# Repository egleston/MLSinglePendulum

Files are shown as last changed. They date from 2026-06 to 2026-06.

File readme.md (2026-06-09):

# Readme
This repository contains all the files needed to build a simple pendulum.
- **Inverted pendulum (English).pdf**: theory of pendulum kinematics and balance control, English version
- **Inverted pendulum (French).pdf**: theory of pendulum kinematics and balance control, French version
- **ComponentList.md**: Bill of material of the machine
- **Single Pendulum STL**: Folder containing all the 3D-print parts in stl format
- **Single Pendulum Circuit**: Folder containing the pcb (schematic + footprint) drawn on Kicad, this circuit allows to connect electrically all the parts together (motor, controller, etc.)
- **Single Pendulum C++**: Folder containing the source code of the controller, written in C++, in VSCode PlatformIO
- **Single Pendulum SwiftUI**: Folder containing the source code of the program on the computer to set-up the system, to set the parameters and to launch the machine, written in SwiftUI, for MacOS computer
- **Single Pendulum Python**: Folder containing the source code written in Python, only the basics intended to control the pendulum from the computer
- **Single Pendulum Drawings pdf**: Folder containing some assembly drawings and some machined part drawings

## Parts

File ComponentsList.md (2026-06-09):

| Number | Quantity | Description | Supplier | Link |
| --- | --- | --- | --- | ---|
| 001 | 1 | Incremental encoder 2500 CPR | AliExpress  | https://de.aliexpress.com/item/1005008882524645.html |
| 002 | 1 | Teethed belt GT2-6mm 2m | AliExpress  | https://de.aliexpress.com/item/10000401582873.html |
| 003 | 1 | Rail MGN12C 600 mm | AliExpress  | https://de.aliexpress.com/item/1000007480470.html |
| 004 | 1 | Microcontroller ESP32-C3 | AliExpress  | https://de.aliexpress.com/item/1005005967641936.html |
| 005 | 1 | Stepper NEMA17" 40 x 40 | AliExpress  | https://de.aliexpress.com/item/4000022185553.html |
| 006 | 2 | Ball bearing 625 5x16x5 | AliExpress  | https://de.aliexpress.com/item/1005008094013486.html |
| 007 | 1 | Screw UNC 1/4-20 length 1" | AliExpress  | https://de.aliexpress.com/item/1005001377376765.html |
| 008 | 1 | Nut UNC 1/4-20 | AliExpress  | https://de.aliexpress.com/item/1005011995082287.html |
| 009 | 1 | Tube brass OD5 x ID4 mm 200mm | AliExpress  | https://de.aliexpress.com/item/1005007123893361.html |
| 010 | 1 | Bar aluminum OD15 100mm | AliExpress  | https://de.aliexpress.com/item/1005006735658783.html |
| 011 | 1 | Threaded bar M5 x 300 mm | AliExpress  | https://de.aliexpress.com/item/1005008168724880.html |
| 012 | 1 | Driver Trinamic TMC5160-BOB | AliExpress  | https://de.aliexpress.com/item/1005008543014443.html |
| 013 | some | Insert nut for plastic M3 | AliExpress  | https://de.aliexpress.com/item/1005007659182107.html |
| 014 | some | Insert nut for plastic M2 | AliExpress  | https://de.aliexpress.com/item/1005007659182107.html |
| 015 | 1 | PCB connect micro and driver | PCBWay | See folder Single Pendulum Circuit |
| 016 | 1 | Wooden base board 800x200x16 mm | DIY shop | |
| 017 | Some | screws | DIY shop | |
| 101 | 1 | BeltFixture | 3D-print | |
| 102 | 1 | CableClamp | 3D-print | |
| 103 | 1 | CableFixture | 3D-print | |
| 104 | 1 | EncoderFixture | 3D-print | |
| 105 | 2 | MotorFlange | 3D-print | |
| 106 | 1 | MotorPulley | 3D-print | |
| 107 | 1 | PulleyFlange | 3D-print | |
| 108 | 1 | ShaftNozzle | 3D-print | |
| 109 | 1 | ShaftWasher | 3D-print | |
| 110 | 1 | Tensioner | 3D-print | |
| 111 | 1 | TensionerBase | 3D-print | |
| 112 | 1 | TensionerPulley | 3D-print | |
| 113 | 1 | BarFixture | Machined | Aluminum, machined from Bar No 010 |
| 114 | 1 | PulleyHub | Machined | Aluminum, machined from Bar No 010 |
| 115 | 1 | TensionerShaft | Machined | Brass, machined from Tube No 009 |

## Assembly

| Number | Quantity | Description | 
| --- | --- | --- |
| 201 | 1 | Single inverted pendulum |
| 202 | 1 | Tensioner assembly |
| 203 | 1 | Carriage assembly | 
| 204 | 1 | Motor's pulley assembly |
| 205 | 1 | Motor assembly |

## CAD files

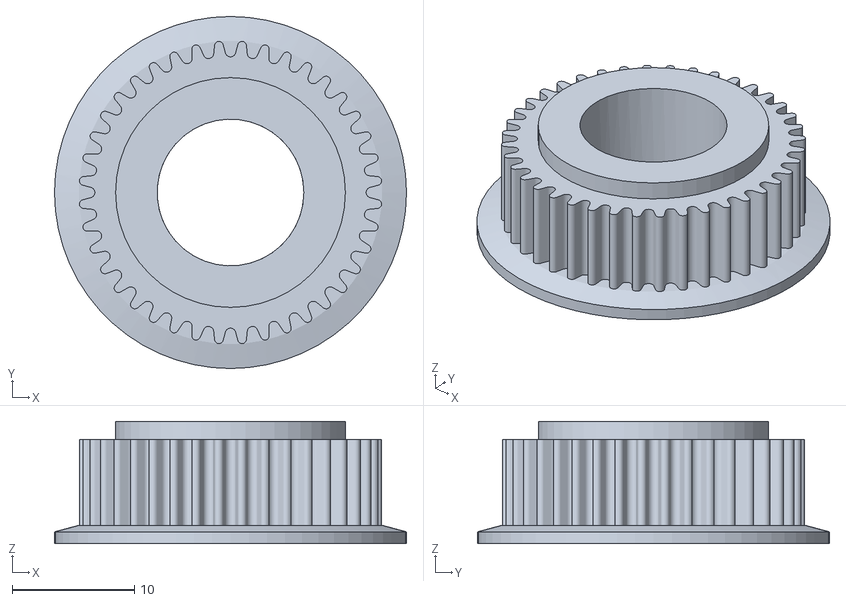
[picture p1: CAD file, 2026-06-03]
Single Pendulum STL/MotorPulley.STL
28.8 x 28.8 x 10.0

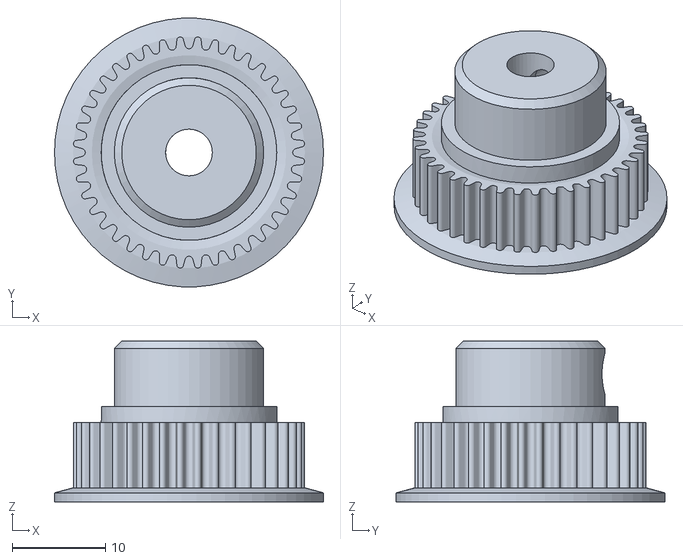
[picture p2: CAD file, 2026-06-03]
Single Pendulum STL/TensionerPulley.STL
28.8 x 28.8 x 17.2

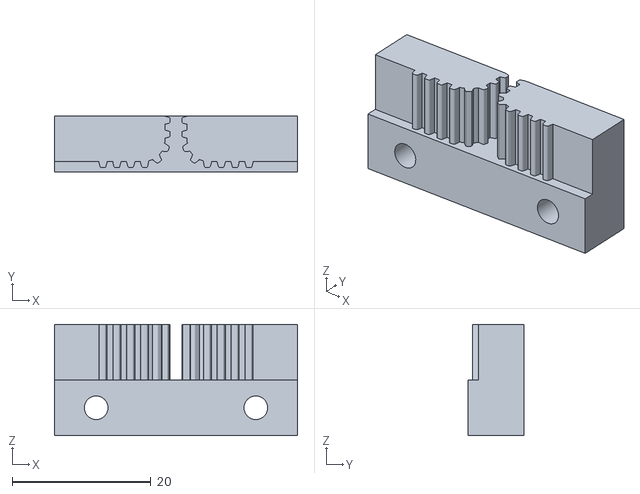
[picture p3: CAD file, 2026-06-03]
Single Pendulum STL/BeltFixture.STL
35.0 x 8.00 x 16.0

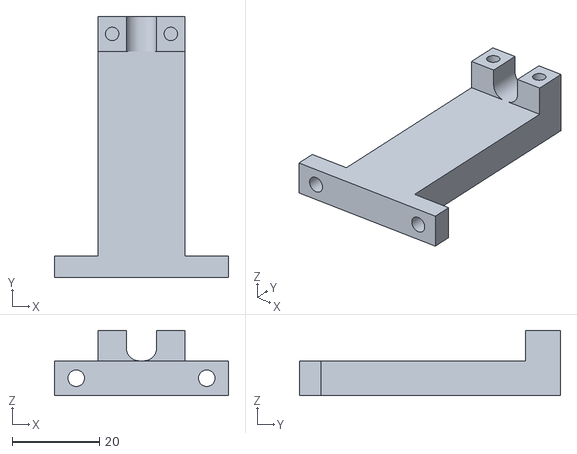
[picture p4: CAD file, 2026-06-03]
Single Pendulum STL/CableFixture.STL
40.0 x 60.0 x 15.0

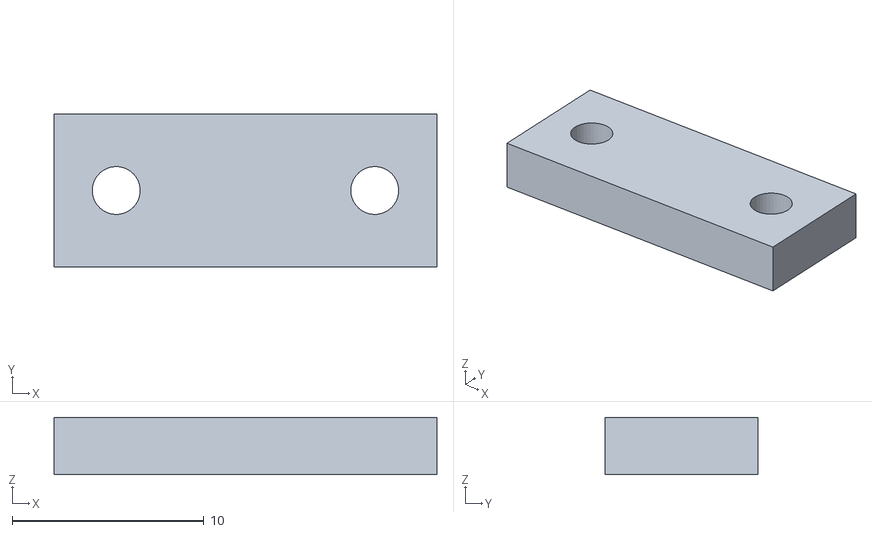
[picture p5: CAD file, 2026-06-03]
Single Pendulum STL/CableClamp.STL
20.0 x 8.00 x 3.00

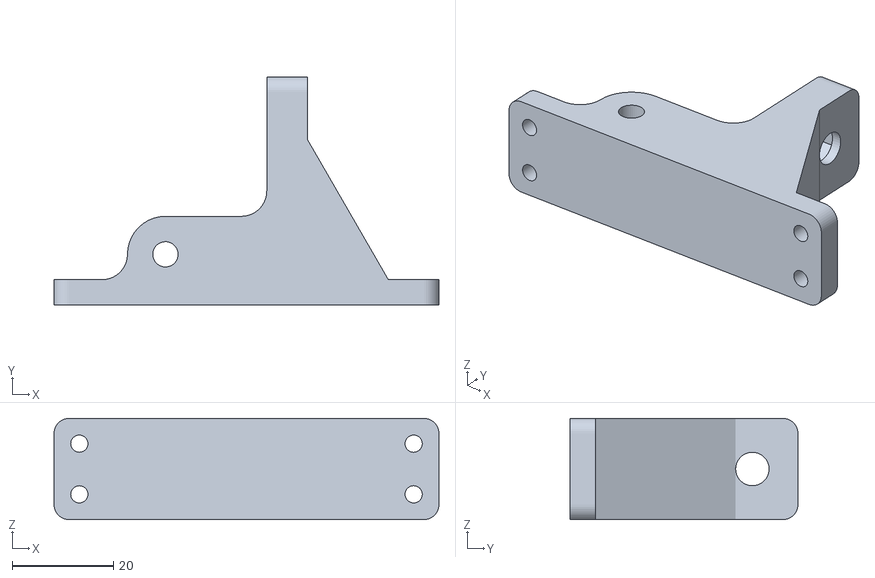
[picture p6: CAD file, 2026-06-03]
Single Pendulum STL/TensionerBase.STL
76.0 x 45.0 x 20.0

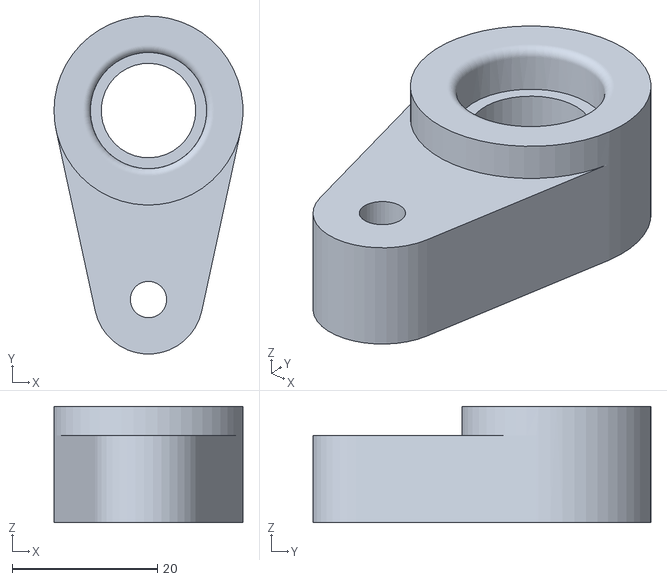
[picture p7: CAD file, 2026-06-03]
Single Pendulum STL/Tensioner.STL
26.0 x 46.5 x 16.0

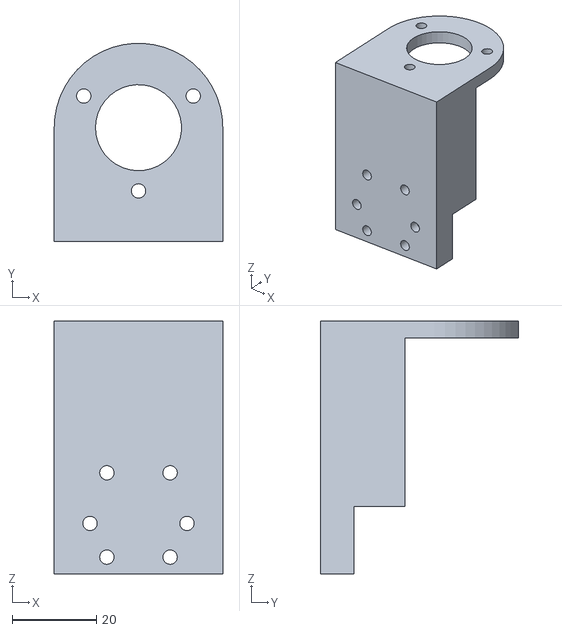
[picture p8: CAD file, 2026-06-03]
Single Pendulum STL/EncoderFixture.STL
40.0 x 47.0 x 60.0

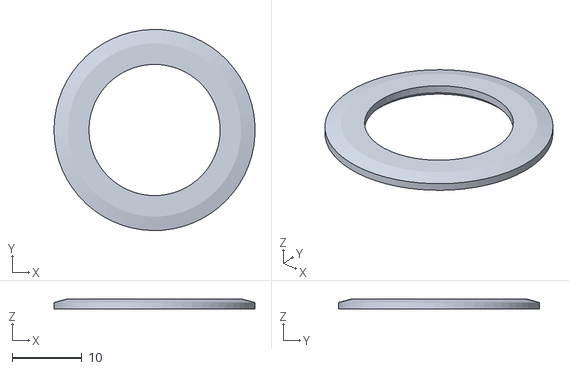
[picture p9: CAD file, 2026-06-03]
Single Pendulum STL/PulleyFlange.STL
28.8 x 28.8 x 1.50

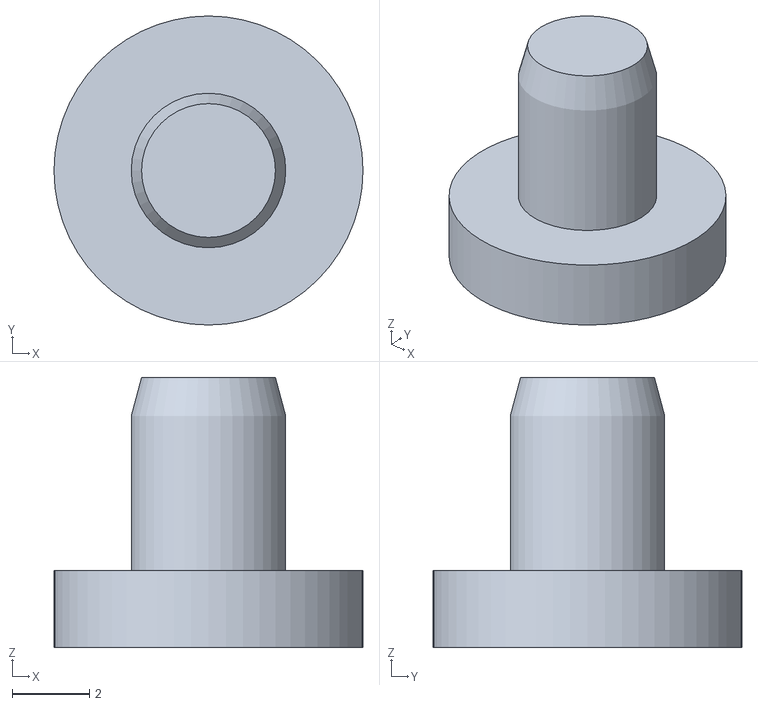
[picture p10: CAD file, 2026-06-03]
Single Pendulum STL/ShaftNozzle.STL
8.00 x 8.00 x 7.00

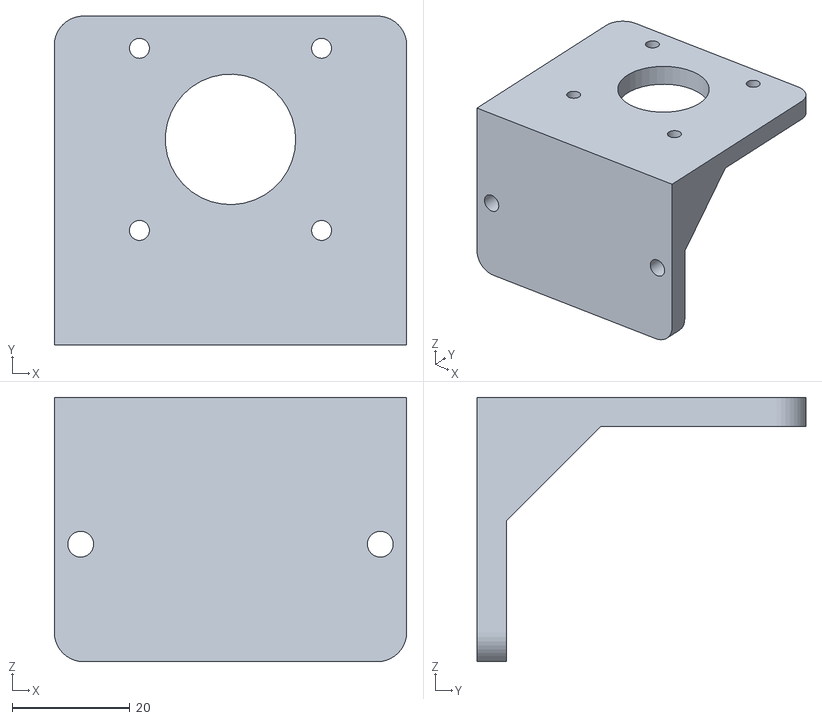
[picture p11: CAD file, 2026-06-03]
Single Pendulum STL/MotorFlange.STL
60.0 x 56.0 x 45.0

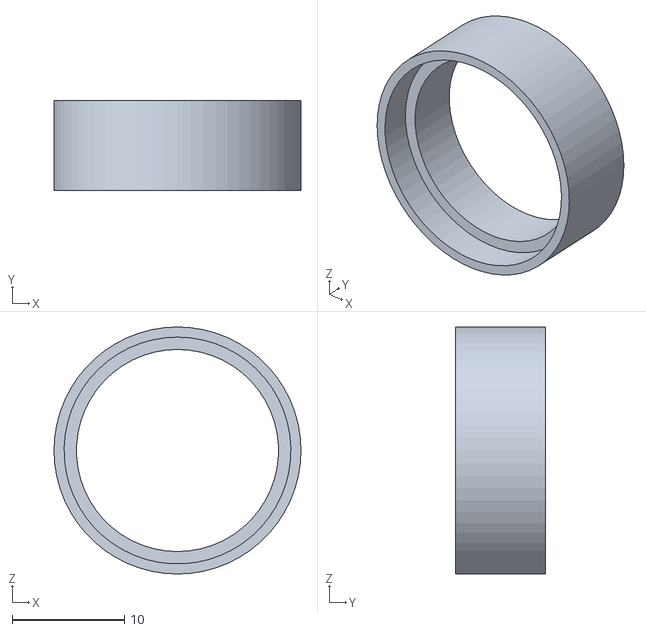
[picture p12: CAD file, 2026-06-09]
Single Pendulum Drawings pdf/WasherEgg.STL
22.0 x 8.00 x 22.0

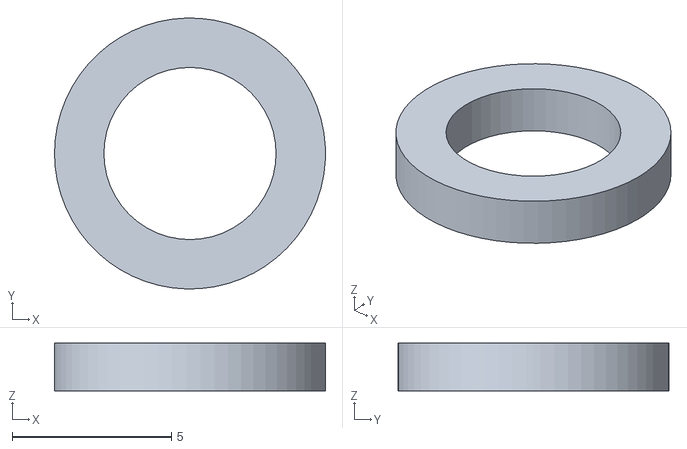
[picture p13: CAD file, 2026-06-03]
Single Pendulum STL/ShaftWasher.STL
8.50 x 8.50 x 1.50

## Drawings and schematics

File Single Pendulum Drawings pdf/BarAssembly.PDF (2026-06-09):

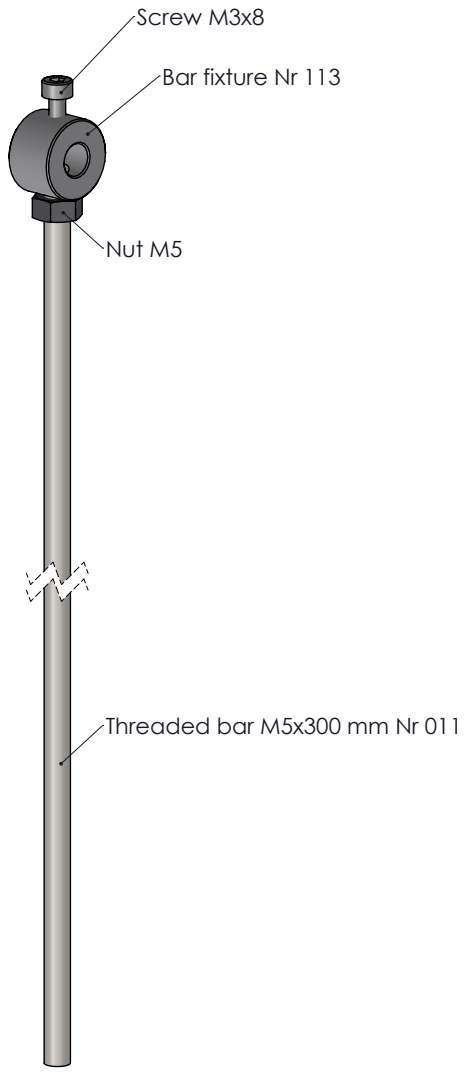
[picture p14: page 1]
Screw M3x8; Nut M5; No dessin; Bar assembly; Dessiné 04.06.2026 - MLa; Echelle 1:1; 04.06.2026 - MLa

Bar fixture Nr 113

Threaded bar M5x300 mm Nr 011

Tolérances ISO 2768-mK

© Ce dessin reste notre propriété et il ne peut être copié, reproduit, communiqué à des tiers ou mis à leur disposition sans notre autorisation écrite.
Bar assembly-M. Laoun-jeudi, 4 juin 2026 20:51:59

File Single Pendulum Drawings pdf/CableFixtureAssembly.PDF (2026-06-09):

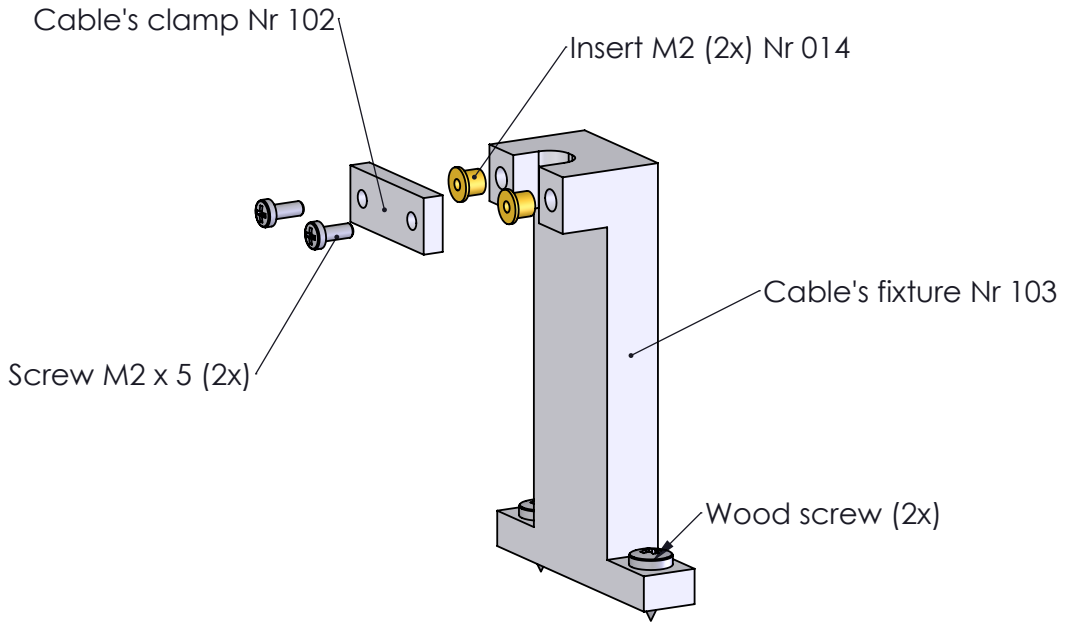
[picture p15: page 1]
Screw M2 x 5 (2x); Insert M2 (2x) Nr 014; Wood screw (2x); No dessin; Cable's fixture assembly; Dessiné 04.06.2026 - MLa; Echelle 1:1; 04.06.2026 - MLa

Cable's clamp Nr 102

Cable's fixture Nr 103

Tolérances ISO 2768-mK

© Ce dessin reste notre propriété et il ne peut être copié, reproduit, communiqué à des tiers ou mis à leur disposition sans notre autorisation écrite.
CableFixtureAssembly-M. Laoun-jeudi, 4 juin 2026 21:14:57

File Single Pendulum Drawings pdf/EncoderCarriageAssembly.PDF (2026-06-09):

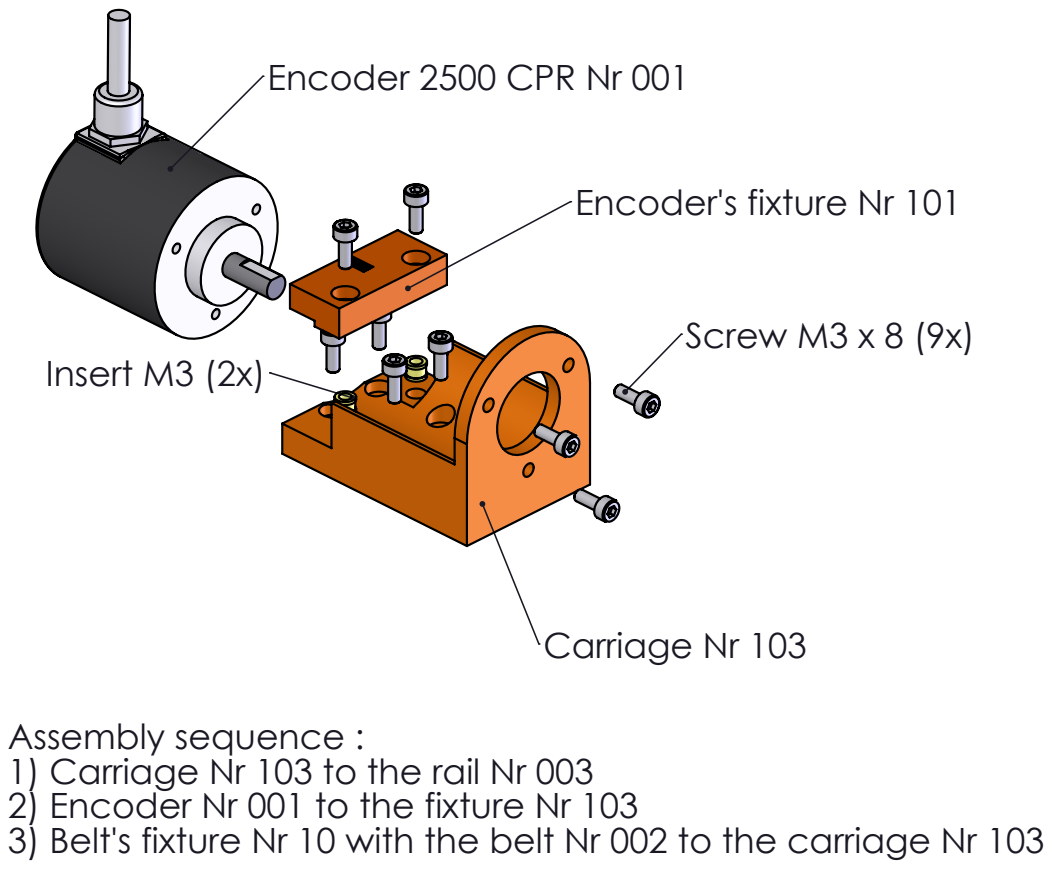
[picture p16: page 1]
Carriage Nr 103; Screw M3 x 8 (9x); Insert M3 (2x); No dessin; Encoder's carriage assembly; Dessiné 04.06.2026 - MLa; Echelle 1:2; 04.06.2026 - MLa

Encoder 2500 CPR Nr 001

Encoder's fixture Nr 101

Assembly sequence :
1) Carriage Nr 103 to the rail Nr 003
2) Encoder Nr 001 to the fixture Nr 103
3) Belt's fixture Nr 10 with the belt Nr 002 to the carriage Nr 103

Tolérances ISO 2768-mK

© Ce dessin reste notre propriété et il ne peut être copié, reproduit, communiqué à des tiers ou mis à leur disposition sans notre autorisation écrite.
EncoderCarriageAssembly-M. Laoun-jeudi, 4 juin 2026 18:43:59

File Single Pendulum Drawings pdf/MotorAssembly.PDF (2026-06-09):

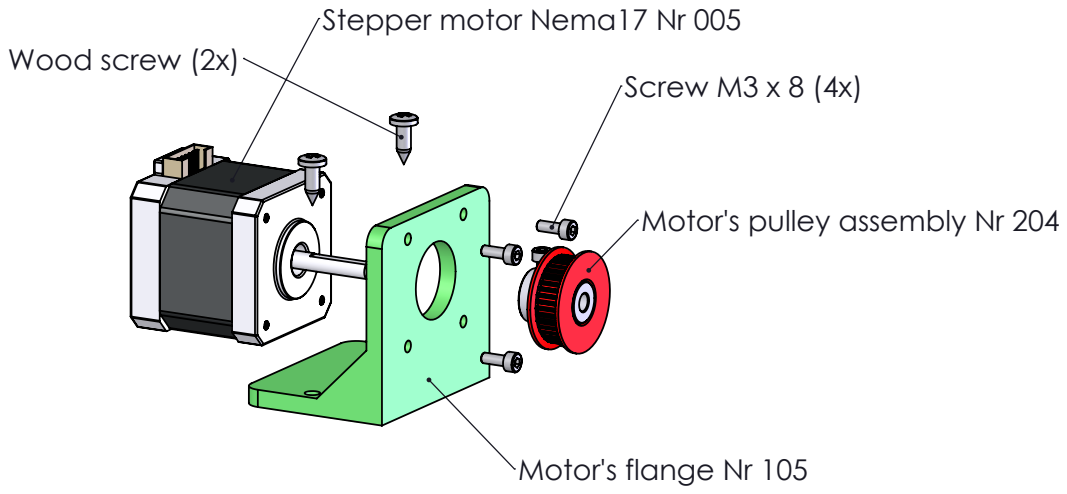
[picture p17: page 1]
Screw M3 x 8 (4x); Wood screw (2x); No dessin; Motor assembly; Dessiné 04.06.2026 - MLa; Echelle 1:2; 04.06.2026 - MLa

Stepper motor Nema17 Nr 005

Motor's pulley assembly Nr 204

Motor's flange Nr 105

Tolérances ISO 2768-mK

© Ce dessin reste notre propriété et il ne peut être copié, reproduit, communiqué à des tiers ou mis à leur disposition sans notre autorisation écrite.
Ass_Motor-M. Laoun-jeudi, 4 juin 2026 17:26:15

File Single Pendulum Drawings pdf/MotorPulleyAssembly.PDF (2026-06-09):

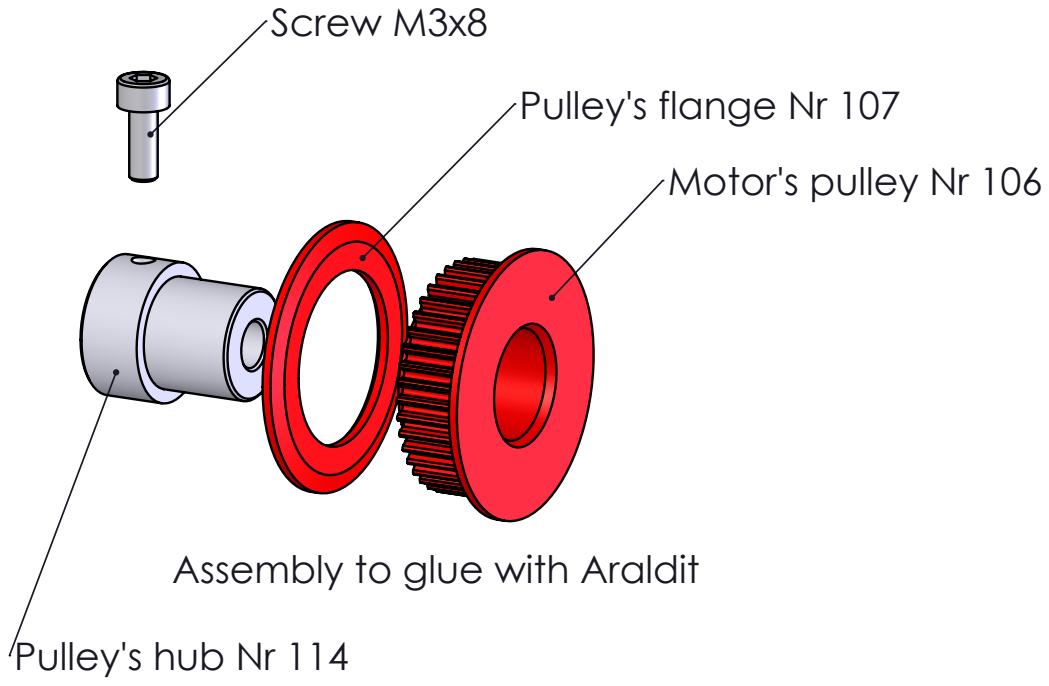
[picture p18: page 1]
Screw M3x8; No dessin; Motor's pulley assembly; Dessiné 04.06.2026 - MLa; Echelle 1:1; 04.06.2026 - MLa

Pulley's flange Nr 107
Motor's pulley Nr 106

Assembly to glue with Araldit

Pulley's hub Nr 114

Tolérances ISO 2768-mK

© Ce dessin reste notre propriété et il ne peut être copié, reproduit, communiqué à des tiers ou mis à leur disposition sans notre autorisation écrite.
MotorPulleyAssembly-M. Laoun-jeudi, 4 juin 2026 18:16:37

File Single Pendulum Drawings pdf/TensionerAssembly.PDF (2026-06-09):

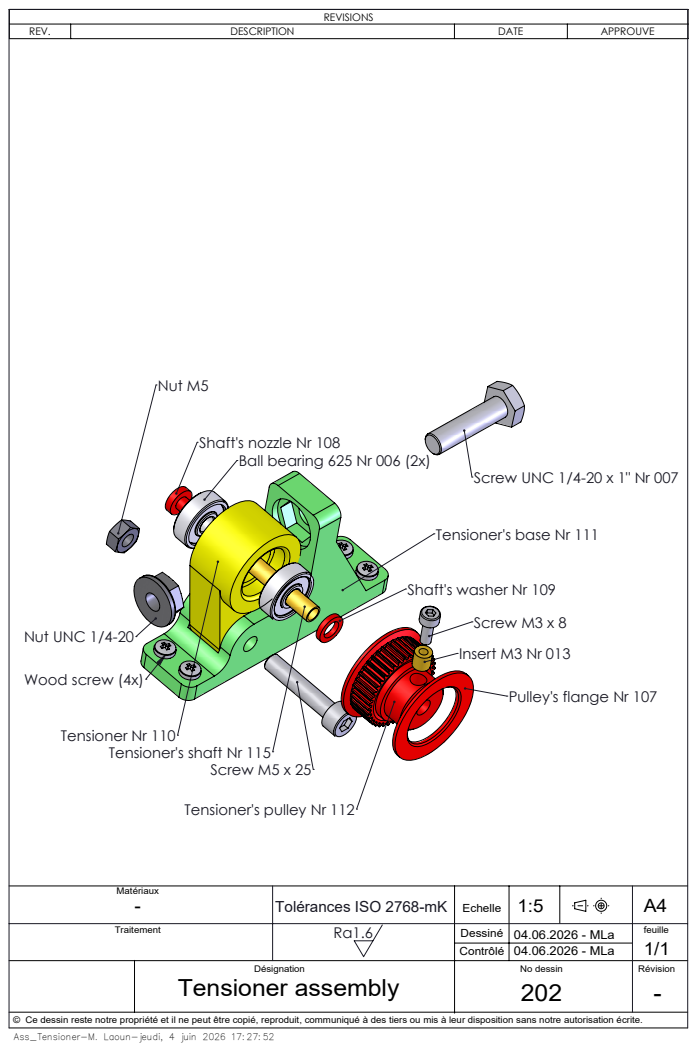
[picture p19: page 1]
Nut UNC 1/4-20; Nut M5; Screw M5 x 25; Screw M3 x 8; Insert M3 Nr 013; Wood screw (4x); No dessin; Tensioner assembly; Dessiné 04.06.2026 - MLa; Echelle 1:5; 04.06.2026 - MLa

Shaft's nozzle Nr 108
Ball bearing 625 Nr 006 (2x)

Screw UNC 1/4-20 x 1" Nr 007

Tensioner's base Nr 111

Shaft's washer Nr 109

Pulley's flange Nr 107

Tensioner Nr 110
Tensioner's shaft Nr 115

Tensioner's pulley Nr 112

Tolérances ISO 2768-mK

© Ce dessin reste notre propriété et il ne peut être copié, reproduit, communiqué à des tiers ou mis à leur disposition sans notre autorisation écrite.
Ass_Tensioner-M. Laoun-jeudi, 4 juin 2026 17:27:52

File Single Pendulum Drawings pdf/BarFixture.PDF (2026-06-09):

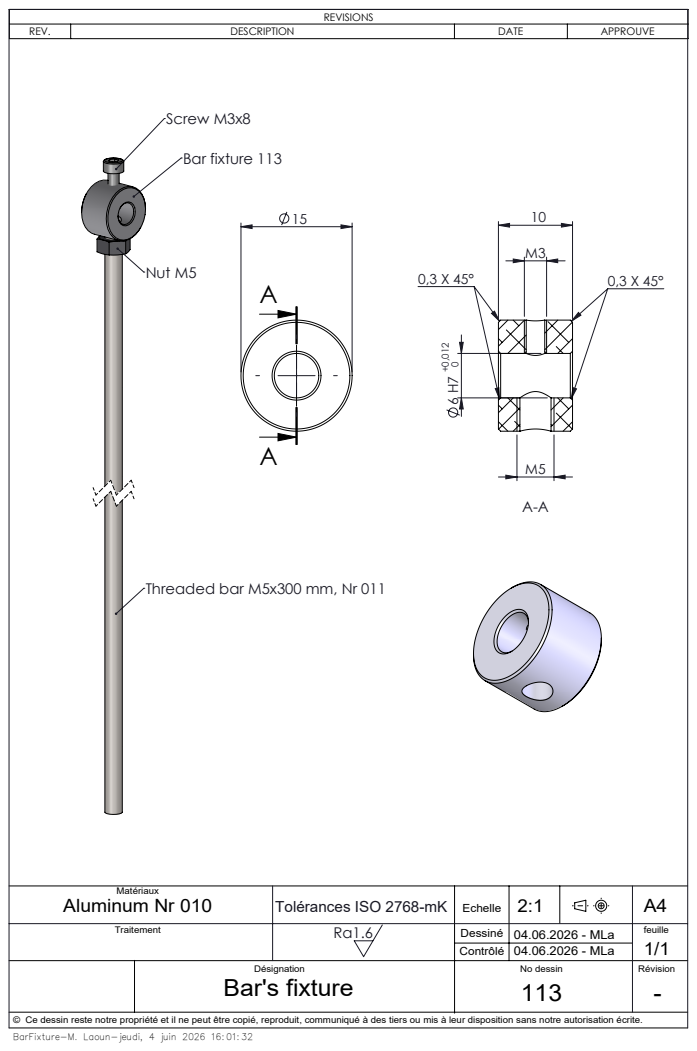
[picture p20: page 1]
Bar fixture 113; Screw M3x8; Nut M5; No dessin; Bar's fixture; Dessiné 04.06.2026 - MLa; Echelle 2:1; Aluminum Nr 010; 04.06.2026 - MLa

Threaded bar M5x300 mm, Nr 011

Tolérances ISO 2768-mK

© Ce dessin reste notre propriété et il ne peut être copié, reproduit, communiqué à des tiers ou mis à leur disposition sans notre autorisation écrite.
BarFixture-M. Laoun-jeudi, 4 juin 2026 16:01:32

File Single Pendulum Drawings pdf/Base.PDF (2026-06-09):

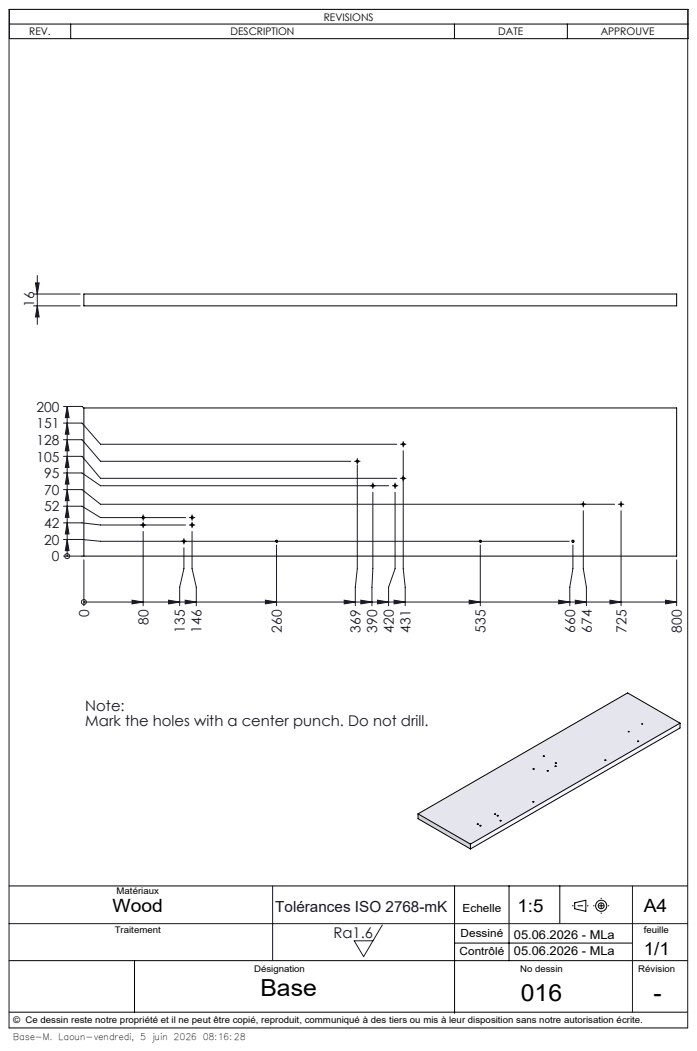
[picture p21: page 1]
No dessin; Dessiné 05.06.2026 - MLa; Echelle 1:5; 05.06.2026 - MLa

Note:
Mark the holes with a center punch. Do not drill.

Tolérances ISO 2768-mK

© Ce dessin reste notre propriété et il ne peut être copié, reproduit, communiqué à des tiers ou mis à leur disposition sans notre autorisation écrite.
Base-M. Laoun-vendredi, 5 juin 2026 08:16:28

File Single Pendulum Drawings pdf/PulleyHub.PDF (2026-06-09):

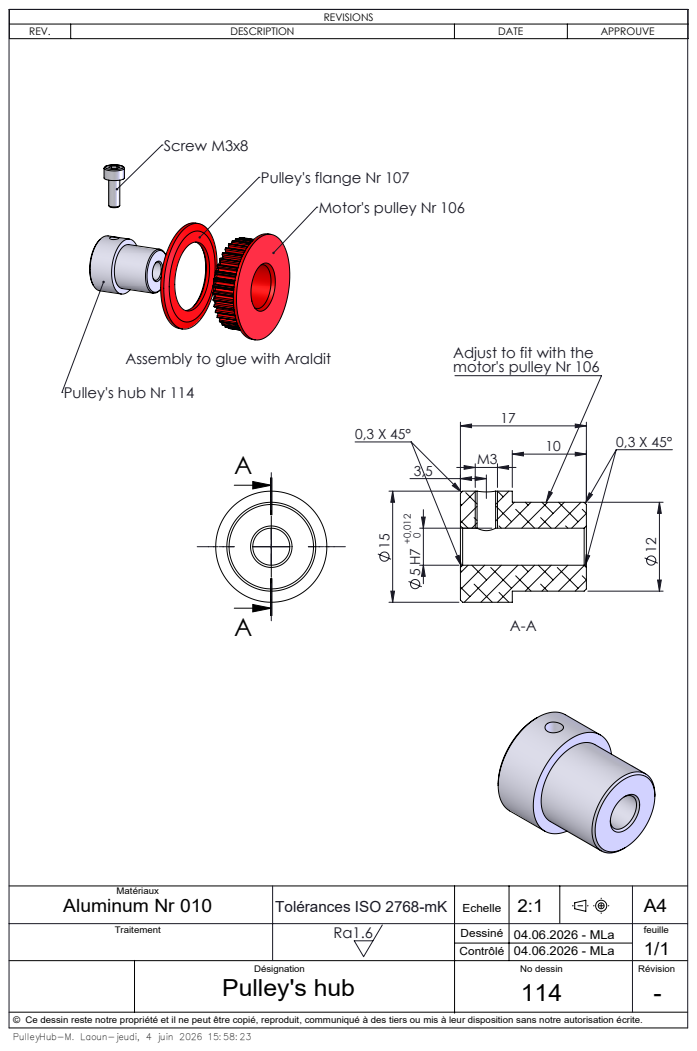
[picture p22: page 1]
Screw M3x8; No dessin; Pulley's hub; Dessiné 04.06.2026 - MLa; Echelle 2:1; Aluminum Nr 010; 04.06.2026 - MLa

Pulley's flange Nr 107
Motor's pulley Nr 106

Adjust to fit with the
motor's pulley Nr 106

Assembly to glue with Araldit

Pulley's hub Nr 114

Tolérances ISO 2768-mK

© Ce dessin reste notre propriété et il ne peut être copié, reproduit, communiqué à des tiers ou mis à leur disposition sans notre autorisation écrite.
PulleyHub-M. Laoun-jeudi, 4 juin 2026 15:58:23

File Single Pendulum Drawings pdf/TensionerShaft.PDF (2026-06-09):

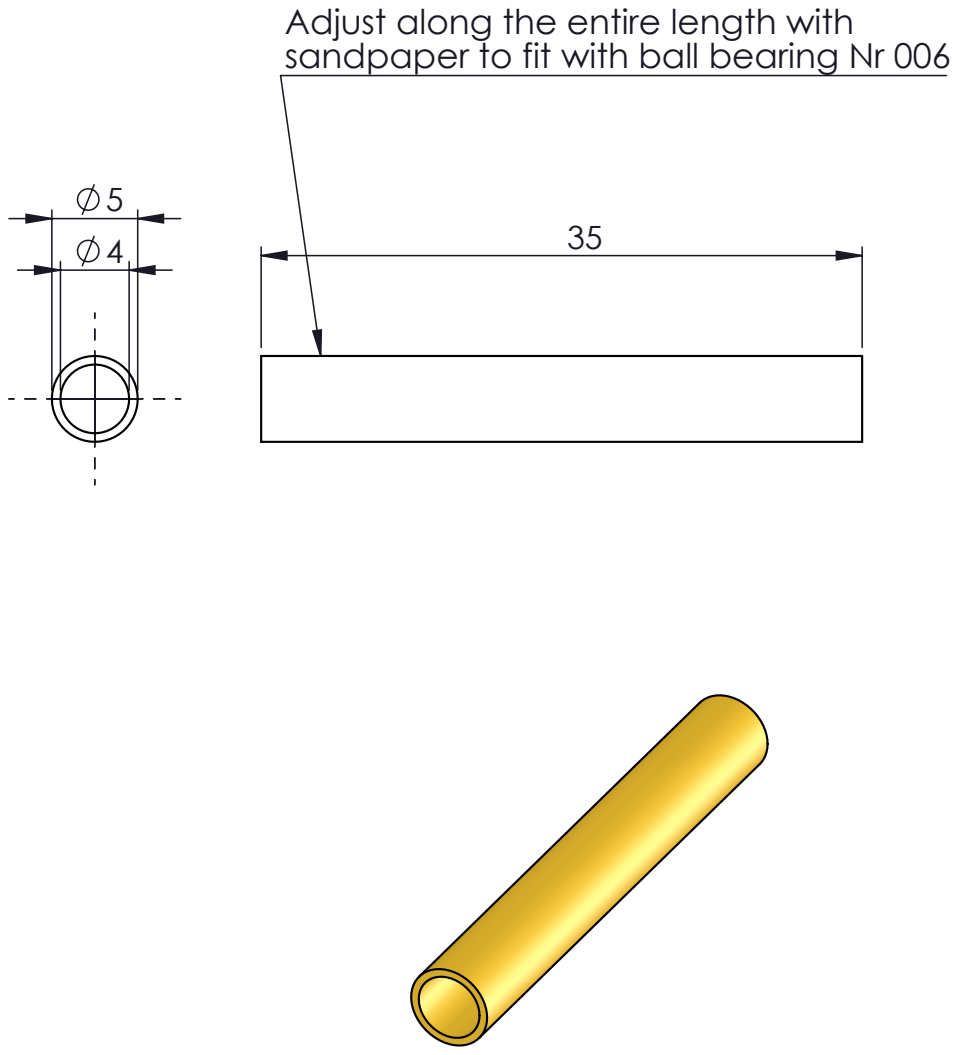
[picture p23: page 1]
No dessin; Tensioner's shaft; Dessiné 04.06.2026 - MLa; Echelle 2:1; Brass Nr 009; 04.06.2026 - MLa

Adjust along the entire length with
sandpaper to fit with ball bearing Nr 006

Tolérances ISO 2768-mK

© Ce dessin reste notre propriété et il ne peut être copié, reproduit, communiqué à des tiers ou mis à leur disposition sans notre autorisation écrite.
TensionerShaft-M. Laoun-jeudi, 4 juin 2026 16:00:36

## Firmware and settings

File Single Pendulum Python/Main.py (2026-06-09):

# Program to control a single inverted pendulum
# using a GUI built with tkinter, 
# and communicating with a microcontroller via serial port
# Author: Magdi Laoun
# Date: 8th of June 2026
import tkinter as tk
from tkinter import ttk
from tkinter import font as tkfont
import MLValue as mlv
import MLValuesManager as mlvm
import MLCustomButton as mlcb
import serial
import MLSerial as mlse
import struct

# ── Main window ─────────────────────────────────────────────────────────────
root = tk.Tk()
root.title("Single inverted pendulum")
root.geometry("800x600")
parameters_manager = mlvm.ValuesManager(values=mlvm.parameters)
results_manager = mlvm.ValuesManager(values=mlvm.readings)
ser = mlse.get_serial_port() # open the serial port (or None if not found)
# ── Fonts ─────────────────────────────────────────────────────────────────
font_title     = tkfont.Font(family="Avenir", size=22)
font_sub_title = tkfont.Font(family="Avenir", size=16)
font_footer = tkfont.Font(family="Avenir", size=12)
font_resultat  = tkfont.Font(family="Courier New", size=15, weight="bold")
# ── Frames ──────────────────────────────────────────────────────────────────
frame_title      = tk.Frame(root)
frame_central    = tk.Frame(root, bg="#ffffff", relief="flat")
frame_parameters = tk.Frame(frame_central, bg="#5272DA", bd=0, relief="flat")
frame_controls    = tk.Frame(frame_central, bg="#999999", relief="flat")
frame_result     = tk.Frame(frame_controls, bg="#DA6452", relief="flat")
frame_footer     = tk.Frame(root, bg="#CECECE", relief="flat")
# ── Layout ──────────────────────────────────────────────────────────────────
frame_title.pack()
frame_central.pack(fill="both", expand=True)
frame_parameters.pack(side="left", anchor = "nw", padx=10, pady=10)
frame_controls.pack(anchor = "nw", padx=10, pady=10)
frame_result.pack(anchor = "n", padx=5, pady=5)
frame_footer.pack(fill="x", side="bottom")
# ── Title ────────────────────────────────────────────────────────────────────
label_title = tk.Label(
    frame_title,
    text="Single pendulum, command",
    font=font_title
)
label_title.pack()
# ── Frame parameters ────────────────────────────────────────────────────────────
def display():
    for value in parameters_manager.values:
        x = value.get_data_to_send()
        try:
            if ser is None:
                return
            ser.write(x)
        except serial.SerialException as e:
            print(f"Error sending parameters: {e}")
label = tk.Label(frame_parameters, text = "Parameters", font = font_sub_title, bg="#5272DA", fg="white")
label.pack(pady=0)
parameters_manager.display(frame_parameters) # display the parameters to be sent to the controller in the parameters frame
btn = mlcb.CustomButton(frame_parameters, text = "Update", command =lambda: display(), bg = "#2E8F4B", fg = "white")
btn.pack(anchor="center", pady=0) # button to send the parameters to the controller
# ── Controls ──────────────────────────────────────────────────────────────────
label = tk.Label(frame_result, text = "Reading values", font = font_sub_title, bg=frame_result.cget("bg"), fg="white")
label.pack(pady=0)
results_manager.display(frame_result) # display the readings from the controller in the result frame
def send_command(address, value):
    value_to_send = bytes([address]) + struct.pack('<f', value)
    try:
        if ser is None:
            return
        ser.write(value_to_send)
    except serial.SerialException as e:
        print(f"Error sending command: {e}")
buttons = [ #list of buttons to send commands to the controller (address + value)
    ("Reset encoder", 0x02, 0.0),
    ("Reset driver",  0x01, 0.0),
    ("Stop",          0x00, 0.0),
    ("Swing-up",      0x00, 1.0),
    #("Balance-up",    0x00, 2.0),
    ("Damping",       0x00, 3.0),
    ("Looping left",  0x00, 4.0),
    ("Looping right", 0x00, 5.0),
]
for text, addr, val in buttons:
    mlcb.CustomButton(
        frame_controls, text=text,
        command=lambda a=addr, v=val: send_command(a, v),
        bg="red", fg="white"
    ).pack(anchor="center", pady=2)

# ── Footer ──────────────────────────────────────────────────────────────
label_footer = tk.Label(
    frame_footer,
    text="Magdi Laoun, 8th of June 2026",
    font=font_footer,
    bg=frame_footer.cget("bg"),
    fg="#2a4a5e"
)
label_footer.pack(side="bottom", pady=16)
display()
def on_packet_received(values): # callback function called when data is received from the controller
    f1, f2, f3, f4, f5, f6 = values
    results_manager.values[0].set_value(f1)  # Angle
    results_manager.values[1].set_value(f2)  # Angular velocity
    results_manager.values[2].set_value(f3)  # Position
    results_manager.values[3].set_value(f4)  # Velocity
    #results_manager.values[4].set_value(f5)  # Cycle time
    #results_manager.values[5].set_value(f6)  # Phase

reader = mlse.SerialReader(ser)  # ser = instance of serial.Serial or None if no port found
reader.start(callback=on_packet_received)

root.mainloop()

reader.stop()  # when closing the application, stop the serial reader thread and close the serial port

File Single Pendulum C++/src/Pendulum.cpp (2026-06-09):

//#include <Arduino.h>
#include "Pendulum.h"
#define CHA GPIO_NUM_5 //Encoder channel A
#define CHB GPIO_NUM_6 //Encoder channel B
#define EN GPIO_NUM_0 //TMC5160 Enable
#define CS GPIO_NUM_4 //TMC5160 Chip select
#define MISO GPIO_NUM_1 //TMC5160 MISO
#define MOSI GPIO_NUM_2 //TMC5160 MOSI
#define SCK GPIO_NUM_3 //TMC5160 Clock
#define CW 1 //Clockwise direction
#define CCW 2 //Counter-clockwise direction
void Pendulum::begin(uint32_t encoderResolution_, uint16_t motorMicrosteps_, uint32_t motorSteps_, float pulleyCircumference_, uint16_t encoderSpeedCount_, uint16_t cartSpeedCount_) {
    encoderResolution = encoderResolution_ ;
    motorMicrosteps = motorMicrosteps_;
    motorSteps = motorSteps_;
    pulleyCircumference = pulleyCircumference_;
    motorSpd.begin(cartSpeedCount_);
    encoderSpd.begin(encoderSpeedCount_);
    encoder.begin(CHA, CHB); //Initialize encoder with pin definitions
    tmc.begin(SCK, MOSI, MISO, CS, EN); //Initialize TMC5160 with pin definitions
    updateRatios();
}
void Pendulum::updateRatios() {
  angleRatio = (2.0f * PI) / static_cast<float>(encoderResolution); // Radians per encoder step
  distanceRatio = pulleyCircumference / (static_cast<float>(motorSteps) * static_cast<float>(motorMicrosteps)); // Meters per motor step
  accelerationRatio = 0.015f / distanceRatio; //Calculate acceleration unit for the motor
  speedRatio = 1.37f / distanceRatio; //Calculate speed unit for the motor
}
void Pendulum::resetEncoder() {
  encoder.resetPosition();
}
void Pendulum::resetTMC() {
  // 0: 256, 1: 128, 2: 64, 3: 32, 4: 16, 5: 8, 6: 4, 7: 2, 8: 1
  switch (motorMicrosteps) {
    case 256: tmc.init(0.05f, 0.4f, 0); break;
    case 128: tmc.init(0.05f, 0.4f, 1); break;
    case 64: tmc.init(0.05f, 0.4f, 2); break;
    case 32: tmc.init(0.05f, 0.4f, 3); break;
    case 16: tmc.init(0.05f, 0.4f, 4); break;
    case 8: tmc.init(0.05f, 0.4f, 5); break;
    case 4: tmc.init(0.05f, 0.4f, 6); break;
    case 2: tmc.init(0.05f, 0.4f, 7); break;
    case 1: tmc.init(0.05f, 0.4f, 8); break;
    default: tmc.init(0.05f, 0.4f, 4); break; //Default to microsteps = 16
  }
}
void Pendulum::updateAngle() {
  angle = float(encoder.getPosition()) * angleRatio;
  angularVelocity = encoderSpd.update(angle);
}
void Pendulum::updatePosition() {
  long currentPosition = tmc.getPosition();
  position = float(currentPosition) * distanceRatio;
  velocity = motorSpd.update(position);
}
void Pendulum::setValue(uint8_t address, float value) {
  switch (address) {
    case 0x00: phase = (static_cast<Phase>(value)); break; //Set phase based on received value
    case 0x01: resetTMC(); break; //Reset TMC5160
    case 0x02: resetEncoder(); break; //Reset encoder position to zero
    case 0x03: setCurrent(value); break; //Set motor current
    case 0x05: xMax = value; break; //Maximum position in meters
    case 0x06: vMax = value; break; //Maximum speed in meters per second
    case 0x07: aMax = value; break; //Maximum acceleration in meters per second squared
    case 0x11: sw[0] = value; break; //position 1 for swing up controller
    case 0x12: sw[1] = value; break; //acceleration 1 for swing up controller
    case 0x13: sw[2] = value; break; //position 2 for swing up controller
    case 0x14: sw[3] = value; break; //acceleration 2 for swing up controller
    case 0x15: sw[4] = value; break; //position 3 for swing up controller
    case 0x16: sw[5] = value; break; //acceleration 3 for swing up controller
    case 0x17: sw[6] = value; break; //threshold for transition from swing up to balance up
    /*
    case 0x10: potEnergy = value; break; //initial potential energy of the pendulum
    case 0x11: kickMagnitude = value; break; //magnitude of initial kick for swing up
    case 0x12: kickAcceleration = value; break; //pulsation of kick for swing up
    case 0x13: ea = value; break; //coefficient energy angle
    case 0x14: ex = value; break; //coefficient energy position
    case 0x15: exd = value; break; //coefficient energy velocity
    case 0x16: threshold = value; break; //threshold from kick to swing up
    */
    
    case 0x20: kpa = value; break; //coefficient proportional gain for encoder
    case 0x21: kda = value; break; //coefficient derivative gain for encoder
    case 0x22: kpm = value; break; //coefficient proportional gain for motor
    case 0x23: kdm = value; break; //coefficient coefficient derivative gain for motor
    case 0x30: m = value*1.2; break; //mass of the pendulum
    case 0x31: l = value; break; //length of the pendulum
    case 0x32: loopingPulse = value; break; //magnitude of position pulse for looping
    case 0x33: balanceDownPulse = value; break; //magnitude of position pulse for balance down
    case 0x34: balanceDownThreshold = value; break; //threshold for angle in radians to transition from balance up to down
    case 0x35: origin = value; break; //origin position for the pendulum
  }
}
void Pendulum::action() {
  if (phase != lastPhase) {
    phaseCounter = 0; //Reset phase counter on phase change
    lastPhase = phase;
    lastPhaseChangeTime = millis();
    lastPosition = position; //Reset last position
  }
  switch (phase) {
    case STANDBY: standby(); break;
    case SWINGUP: swingUp(); break;
    case BALANCEUP: balanceUp(); break;
    case BALANCEDOWN: balanceDown(); break;
    case LOOPINGCW: looping(CW); break;
    case LOOPINGCCW: looping(CCW); break;
  }
}
void Pendulum::standby() {
  tmc.setRampMode(0); //Set to position mode
  tmc.setAcceleration(aMax * accelerationRatio); //Set acceleration to maximum
  tmc.setSpeed(vMax * speedRatio); //Set speed to maximum
  tmc.targetPosition(0); //Set target position to zero
}
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

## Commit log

2026-06-03 Change of list of components, adding the detail of the stl parts, change of stl folder (name in english)
    [BeltFixture.STL, CableClamp.STL, CableFixture.STL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]
2026-06-09 Adding pdf drawings and python program
    [WasherEgg.STL]
